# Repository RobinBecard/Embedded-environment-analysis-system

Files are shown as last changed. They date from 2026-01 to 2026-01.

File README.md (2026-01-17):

# Embedded Environment Analysis System




## Overview

This project is an **Autonomous Environmental Analysis Robot** designed to explore and monitor air quality in real-time. Built on an Arduino Mega platform, it integrates professional-grade sensors to measure atmospheric pressure, temperature, and multiple hazardous gases (CO, Smoke, CH4, Propane).

The system features a modular firmware architecture, separating motor control logic from sensor processing, making it highly maintainable and scalable.

---

## The System

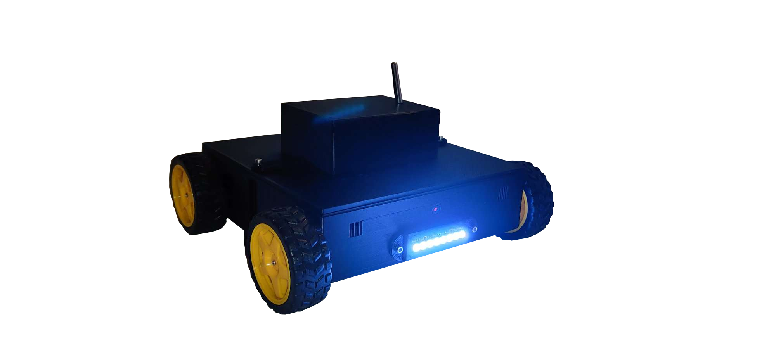
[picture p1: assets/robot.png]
System Photo

*Figure 1: Mobile analysis platform equipped with gas sensors and NeoPixel status indicators.*

---

## Key Features

* **Multi-Gas Detection:** Real-time PPM calculation for CO, Smoke, Methane, and Propane using calibrated MQ-series sensors.
* **Precision Telemetry:** Integration of the DFRobot ICP10111 for high-accuracy barometric pressure monitoring.
* **Modular Drive System:** 4-motor DC drive controlled via Adafruit Motor Shield, supporting full omnidirectional movement.
* **Visual Feedback:** 8-pixel NeoPixel LED strip for status signaling and alerts.
* **Remote Command Interface:** Serial-based control protocol for movement and data triggering.

---

## Hardware Components

| Component | Description |
| :--- | :--- |
| **Microcontroller** | Arduino Mega 2560 |
| **Motor Driver** | Adafruit Motor Shield (L293D based) |
| **Pressure Sensor** | DFRobot ICP10111 |
| **Temp Sensor** | DS18B20 (OneWire) |
| **Gas Sensors** | MQ-2 (Smoke/LPG), MQ-7 (CO) |
| **Illumination** | Adafruit NeoPixel Stick (8 RGB LEDs) |

---

## Project Structure

```text
Embedded-environment-analysis-system/
```text
Embedded-environment-analysis-system/
│   README.md
│   
├───app
├───assets
│   │   robot.png
│   │   
│   ├───arduino_mega/
│   │       
│   ├───battery
│   ├───bmp280_pressure_sensor/
│   │
│   ├───ds18b20_temp_sensor/
│   │
│   ├───esp32_cam/
│   │
│   ├───l293d/
│   │
│   └───motor/
├───docs/
│   │
│   └───datasheets/
│
├───EnvironmentalRobot_Firmware/
│   │
│   └───BTconfig/
│
└───mechanical
    ├───3d_printing/
    │
    └───components
        ├───arduino_mega/
        │
        ├───battery/
        │
        ├───bmp280_pressure_sensor/
        │
        ├───ds18b20_temp_sensor/
        │
        ├───l293d/
        │
        └───motor/
```

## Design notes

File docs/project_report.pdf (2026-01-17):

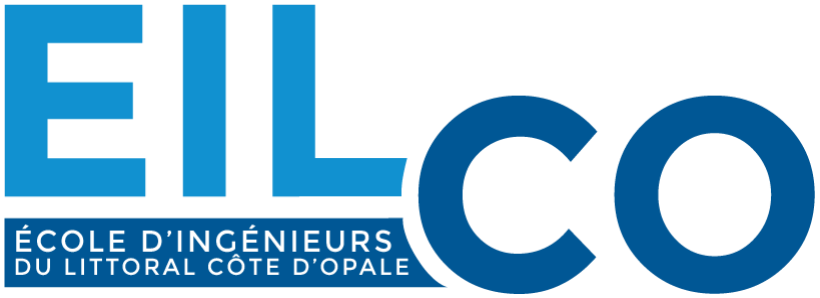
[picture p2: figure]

# Rapport de Projet “Système embarqué d’analyse d’environnement”

### Réalisé par:

### Robin BECARD Axel GROGNET Rémi DAMBRICOURT

### Professeur référent:

### André BIGAND

## Sommaire

## I/ Introduction

## II/ Organisation du projet

## - Dates limites

## III/ Cahier des charges

## - Objectifs - Contraintes, solutions et schémas fonctionnel - Comptes rendus de séances

## I/ Introduction

Dans un monde où l’insécurité ne cesse d’augmenter en partie à cause des catastrophes météorologiques, les services de secours sont en constante action. C’est ainsi que nous avons décidé d’intervenir pour assister ces services.

En effet, le but de ce projet est de réaliser un robot pouvant accéder à des zones restreintes et/ou dangereuses pour l’Homme. Il sera donc utile pour les secours en général lors d'événements catastrophiques (tremblement de terre, éboulement, etc) afin de détecter différentes fuites de gaz et de pouvoir observer ce qu’il s’y passe.

Notre objectif est de créer un prototype testable dans différents milieux afin de pouvoir l’améliorer pour une potentielle mise en vente. Les matériaux utilisés ne seront donc pas forcément les plus optimisés pour le projet vis-à-vis du temps et du budget que nous possédons pour le réaliser. De plus, le prototype ne sera pas étanche pour pouvoir réaliser une démonstration le jour de la soutenance.

## II/ Organisation du projet

### Dates Limites

Pour le bon avancement du projet, nous avons décidé de tout organiser en un planning pour le suivre le plus fidèlement possible.

Pour la commande des pièces, nous avons fixé la date du 15 octobre 2022 dans l’optique de pouvoir s’attaquer au montage du robot et aux différents tests avec le matériel. Nous avons envoyé la commande à Mr Ghislain le 14 octobre 2022.

Pour le montage du robot et des différents modules arduino, nous avions pour but de commencer vers le 30 octobre 2022, sauf que nous avons rencontré un problème. La commande est partie bien trop tard pour espérer commencer à cette date.
Pour pallier ce problème, nous avons décidé d’utiliser le matériel que nous avions déjà grâce à Robin BECARD pour commencer les différents tests du code Arduino que nous avons commencé à écrire entre la commande et la réception des composants.

Pour ce qui est du pré-rapport et du rapport final, nous sommes contraints de les rendre respectivement le 11 novembre 2022 et le jeudi 4 janvier 2023, dates que nous allons respecter.

La soutenance du projet se passera, sauf changement de date, le 11 janvier 2023.

## III/ Cahier des charges

### Objectifs

Ce projet doit répondre à 4 objectifs principaux :

- Se déplacer à distance sur plusieurs mètres
- Retourner un flux d’informations grâce aux capteurs via une “Interface Homme Machine” (IHM)
- Envoyer un flux vidéo en direct

### Contraintes et solutions

Pendant nos recherches, notre projet a été soumis à plusieurs contraintes auxquelles nous avons dû palier.

Premièrement, notre système embarqué est sensible aux intempéries, pour contrer cela nous avons décidé de réaliser un châssis et une protection pour contrer la pluie ou bien tout débris qui serait susceptible de tomber sur le robot. Pour que notre projet soit vraiment étanche, il faudrait venir colmater toutes ouvertures, mais nous ne le ferons pas pour agir facilement si nous avons un problème de pièces et pour pouvoir l’ouvrir le jour de la soutenance.

De plus, il doit également pouvoir se déplacer dans toutes les directions. Nous nous sommes donc penchés sur plusieurs solutions: le choix des chenilles fut énoncé en 1er mais fut vite écarté car trop complexe à mettre en œuvre. Le choix le plus évident était alors d’équiper notre système embarqué de 4 roues chacune équipé d’un moteur.

Il doit également être alimenté de façon continue et posséder une certaine autonomie. Nous sommes restés sur un choix assez simple, une batterie pour la carte arduino et les capteurs et une autre pour les moteurs, en effet ceux-ci consomment beaucoup et le robot doit garantir une autonomie suffisante pour ne pas tomber en panne. Mais suite à un problème avec la commande, nous n’avons qu’une seule batterie pour l’ensemble du système. Pour contrer cela, nous utiliserons une pile pour alimenter l'ESP 32-CAM.

La communication entre l’interface et le robot doit être rapide afin de garantir un bon contrôle du véhicule. L’utilisation d’une communication filaire était une des solutions prise en compte mais celles que l’on va privilégier sont la communication WIFI pour recevoir la vidéo et le Bluetooth afin de recevoir les informations des capteurs mais aussi d’envoyer les commandes de déplacement au robot. Cette technologie est contrainte à une certaine portée mais cela empêche le robot de se coincer avec un câble.

Afin de donner vie à notre système nous avons décidé de lui incorporer différents modules, tout d’abord le module ESP32-CAM, c’est ce qui va permettre d’envoyer en WIFI le flux vidéo de la caméra directement sur l’adresse http que générera l’ESP. Nous avons ensuite un module Bluetooth HC-05 qui permet de relier l’arduino, les moteurs et les capteurs directement à l’application sur téléphone. Notre robot étant tout d’abord un système d’analyse d’environnement, il lui fallait des capteurs afin de nous renvoyer des informations en direct sur son environnement. On l’a donc équipé d’un capteur de température, d’un capteur de pression et enfin 2 capteurs de gaz (un, spécifique au monoxyde de carbone, gaz plus compliqué à détecter par sa taille; et un autre plus général).

Pour mieux illustrer les solutions trouvés vous pouvez voir en annexe un schéma fonctionnel réalisé par nos soins (voir Figure 1).

### Compte rendu des séances

Afin de tenir compte de notre avancement, nous avons rédigé des rapports à la fin de chaque séance. Nous les avons condensés pour obtenir un texte plus lisible.

Lors de la première séance, le groupe a réfléchi sur les différents problèmes et solutions énoncés dans la partie “Contraintes et solutions” se situant plus haut dans le rapport. Pendant cette séance, on a sorti un premier schéma assez sommaire qui fut une base pour le schéma fonctionnel final. Cette première séance a grandement aidé pour la deuxième car nous avons directement commencé la recherche des différents composants nécessaires pour la bonne réalisation du projet.
A la séance d’après, nous avons eu une petite réunion avec notre référent pour lui tenir compte de notre avancement ainsi que de nos ambitions pour le projet, c’est notamment lui qui nous a décidé sur le choix de la communication bluetooth.
Après, nous avons pris le temps de créer une liste du matériel avec les intitulés exacts de chaque pièce et un lien pour trouver la dite pièce sur internet (voir Figure 2). C’est à ce moment-là qu'on a pris le temps de faire le schéma fonctionnel du robot.
La commande transmise à M. Ghislain, nous devions attendre l’arrivée des pièces. Pendant cette attente, on a commencé à coder différentes fonctions sur le fonctionnement des capteurs et des moteurs. Pour les tester, le site Tinkercad fut d’une grande aide. Grâce à ce dernier, on a pu simuler les différents composants que le robot possèdera à terme et vérifier leur bon fonctionnement. Le code pour demander au robot de se déplacer dans une direction ainsi que pour les capteurs est valide. (voir Figures 3, 4 et 5).
Lors des séances suivantes, on a commencé les tests avec le peu de matériel que nous avions à disposition et on a finalisé le pré-rapport. En annexes, on peut notamment voir différentes photos sur les capteurs, les moteurs et enfin une vision globale du montage avec les composants possédés avant le pré-rapport. (voir Figures 6, 7, 8, 9, 10 et 11)

Après cela, notre équipe s’est attaquée à la conception du châssis en impression 3D (voir Figures 12 et 13).
Suite à cela, nous avons récupéré les pièces manquantes dont l’ESP32-CAM, le module moteur arduino et les capteurs restants.
Entretemps, nous avons également trouvé comment résoudre notre plus gros problème, l’IHM. Nous avons trouvé un site nommé MIT App Inventor (https://appinventor.mit.edu) qui nous permet de créer notre propre application en codant par blocs et en connectant le lien http de l’ESP32-CAM par Bluetooth.
Après une autre séance et pas mal de travail pendant les vacances de Noël, nous avons finalement imprimé le châssis et continué l’IHM, cependant nous avons eu une contrainte technique sur le site qui nous empêche de recevoir à la fois la vidéo et les informations des capteurs. Pour pallier temporairement à ce problème nous avons décidé d’utiliser 2 appareils, l’un pour les commandes et les capteurs et l’autre pour la vidéo. (voir Figures 14, 15, 16)

Afin de retracer plus facilement l’avancement du projet, vous trouverez en annexe un diagramme de Gantt relatant nos recherches au cours du temps (voir Figure 17).

## Remerciements

Nous remercions notre référent Mr Bigand, pour son aide, son partage de connaissance en Arduino mais aussi pour nous avoir fourni du matériel que l’école n’a pas pu nous procurer. Nous remercions aussi Mr Poncin pour l’achat des pièces nécessaires à la fabrication du projet. Enfin nous remercions l’école de nous avoir permis de réaliser ce projet et pour nous avoir financé.

## Annexes

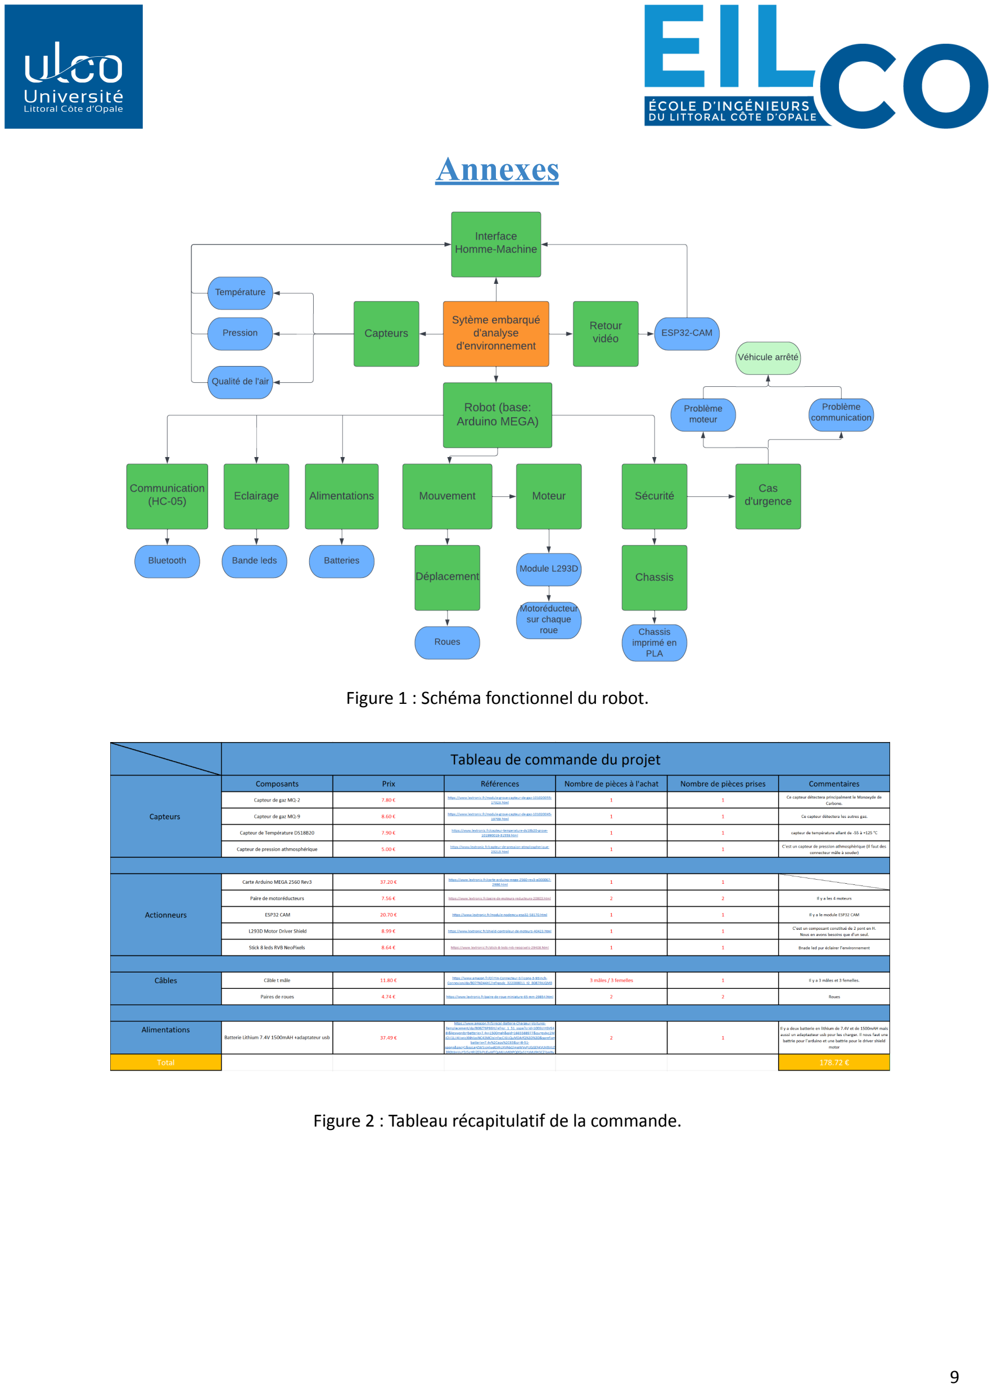
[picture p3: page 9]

Figure 1 : Schéma fonctionnel du robot.

Figure 2 : Tableau récapitulatif de la commande.

## Annexes

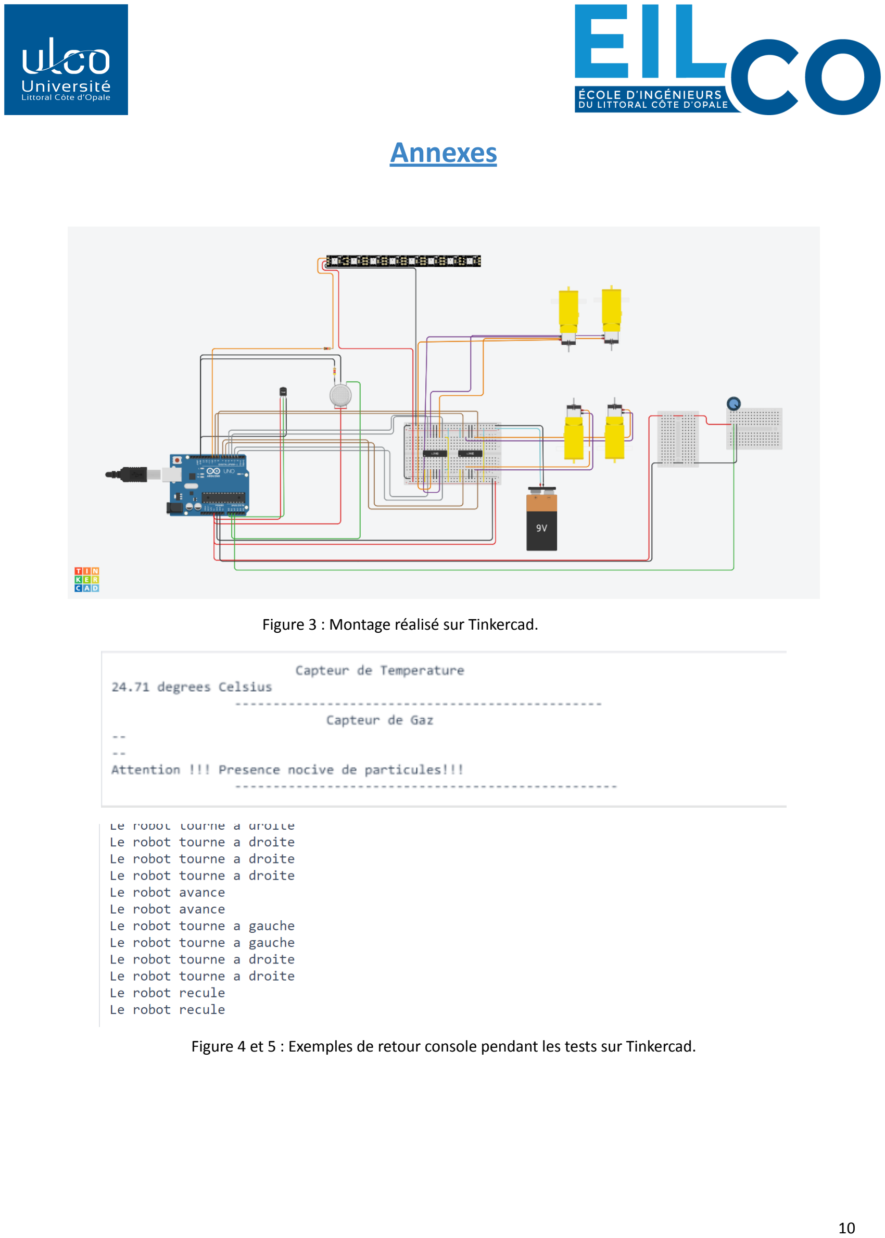
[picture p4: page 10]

Figure 3 : Montage réalisé sur Tinkercad.

Figure 4 et 5 : Exemples de retour console pendant les tests sur Tinkercad.

## Annexes

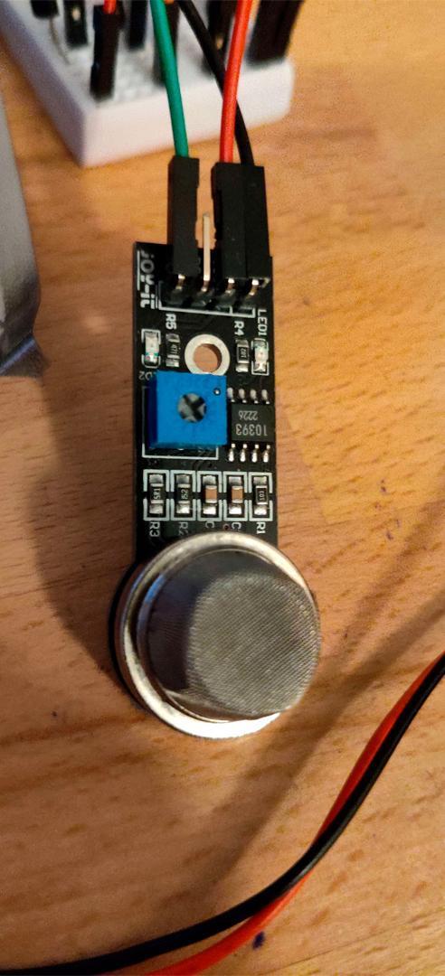
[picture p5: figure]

Figure 6 : Capteur de gaz.

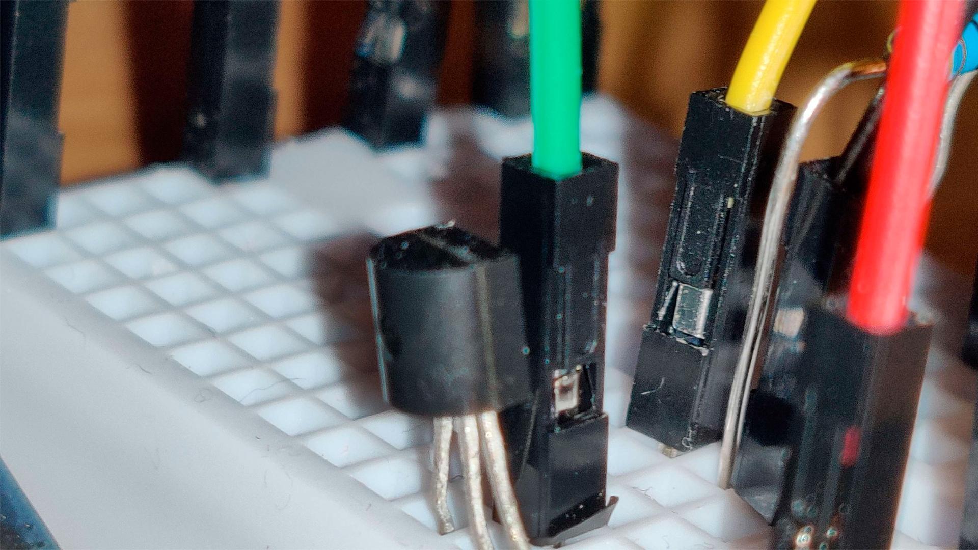
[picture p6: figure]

Figure 7 : Capteur de température.

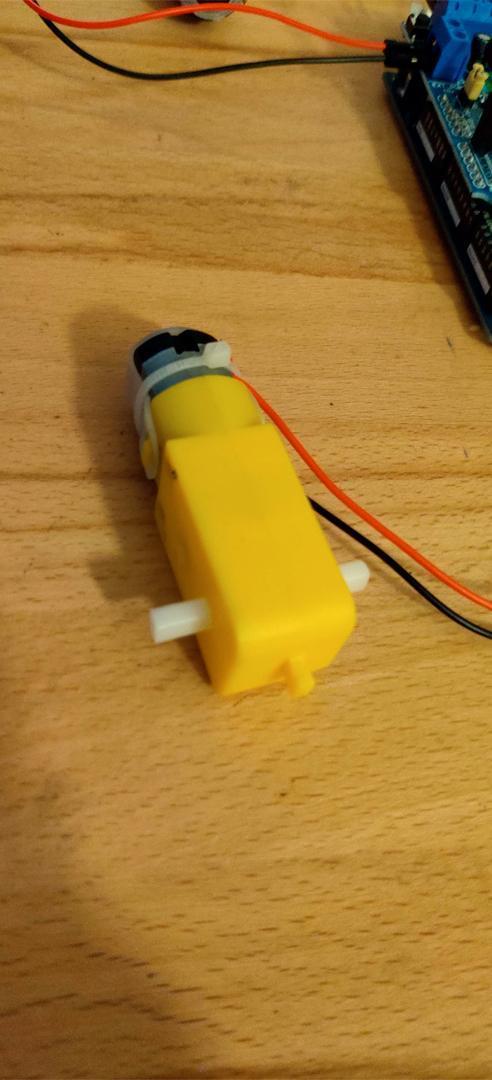
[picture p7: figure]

Figure 8 : Un des motoréducteurs qui contrôlera les roues.

## Annexes

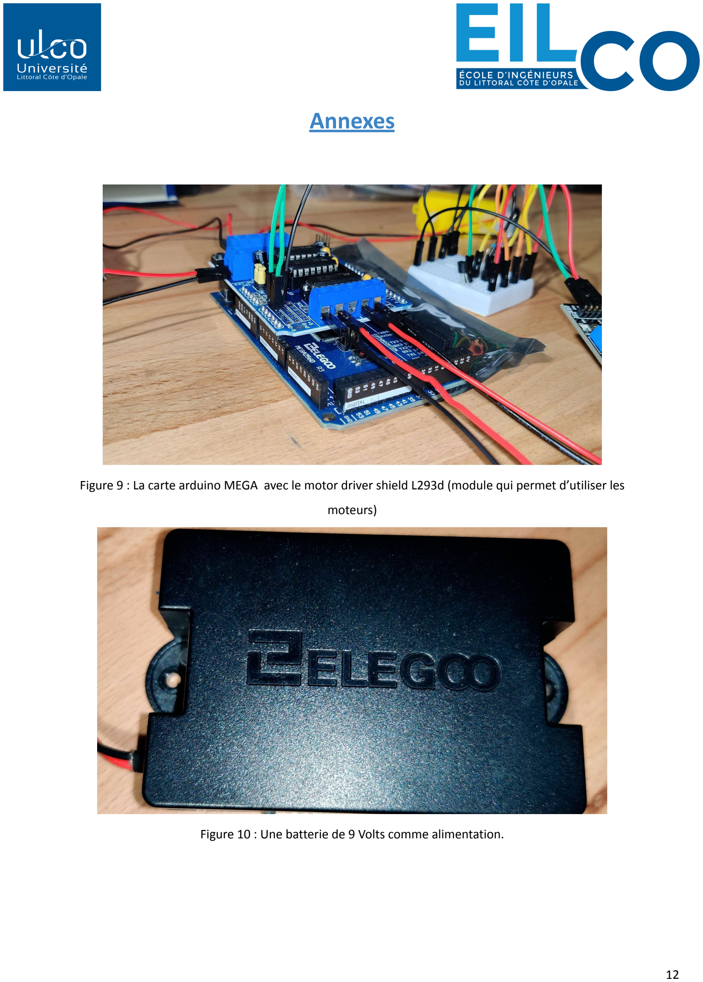
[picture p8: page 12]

Figure 9 : La carte arduino MEGA avec le motor driver shield L293d (module qui permet d’utiliser les

moteurs)

Figure 10 : Une batterie de 9 Volts comme alimentation.

## Annexes

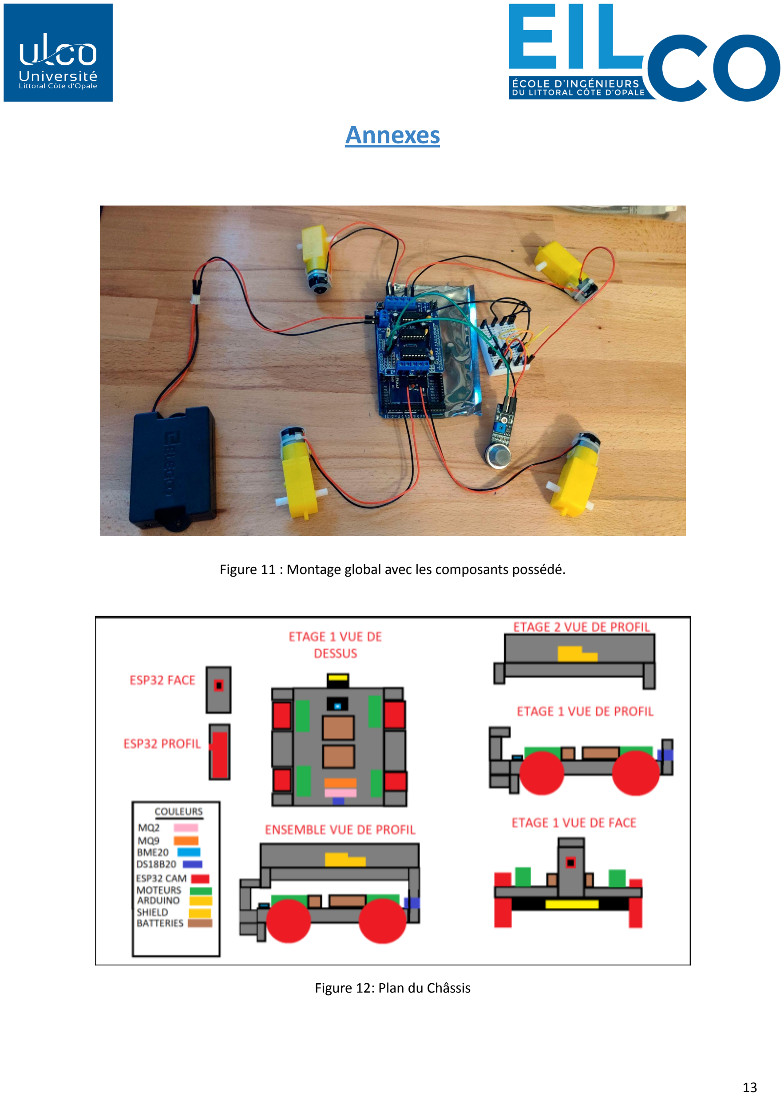
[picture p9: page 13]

Figure 11 : Montage global avec les composants possédé.

Figure 12: Plan du Châssis

## Annexes

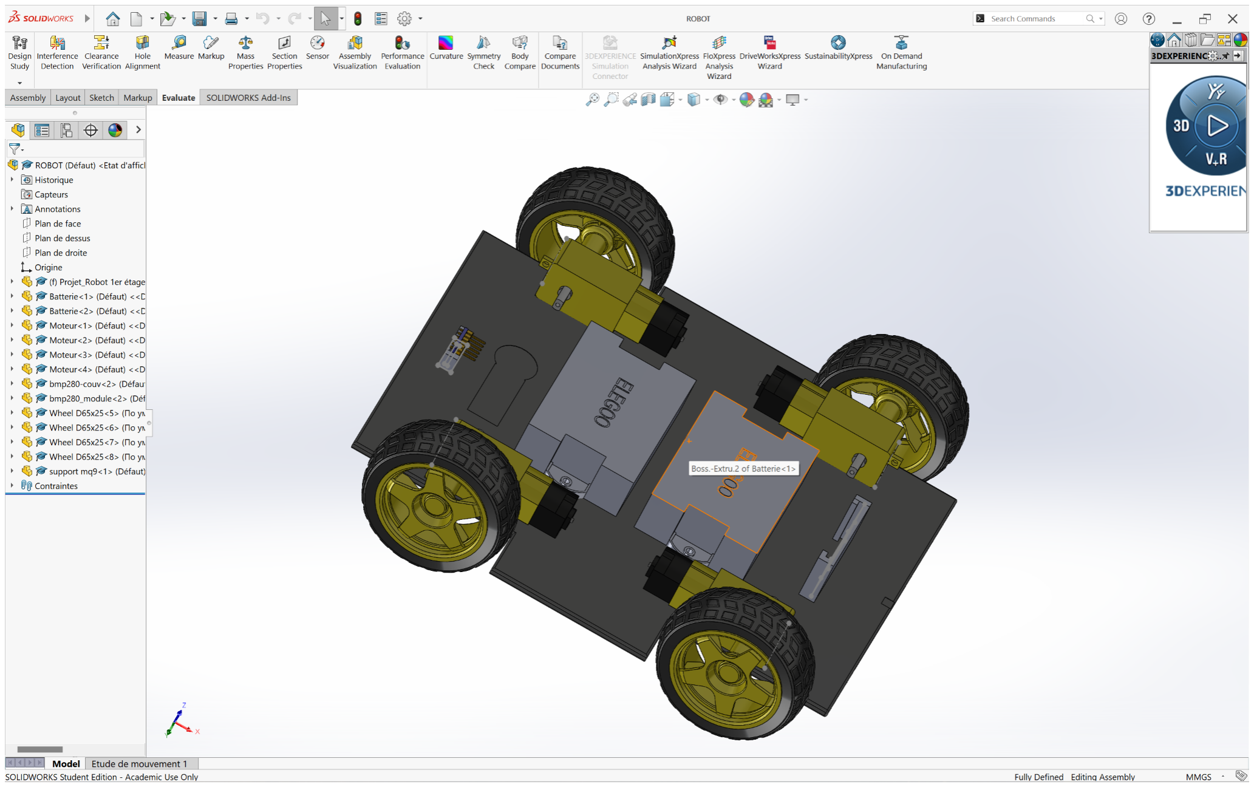
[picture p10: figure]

Figure 13: Châssis en 3d sur SolidWorks

## Annexes

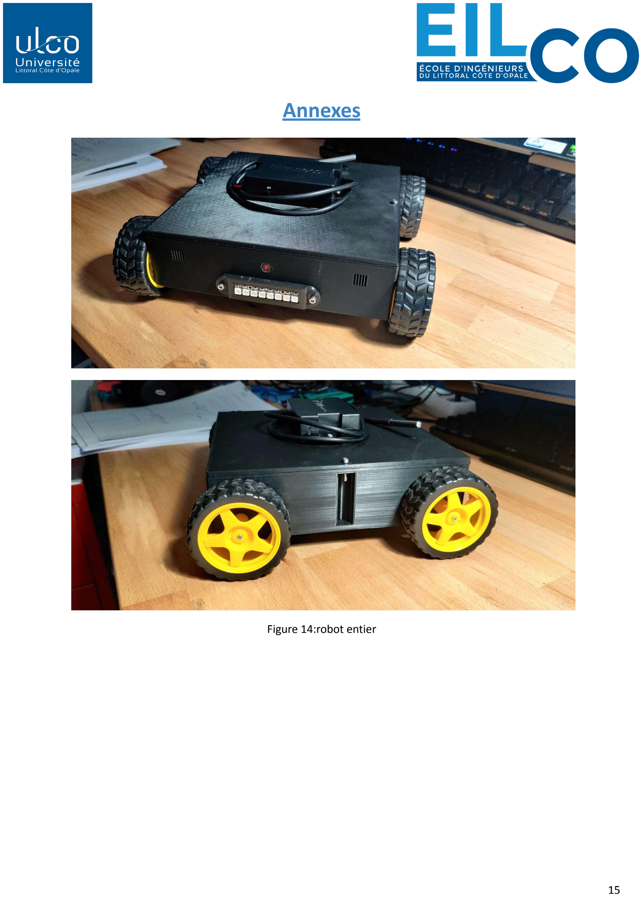
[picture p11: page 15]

Figure 14:robot entier

## Annexes

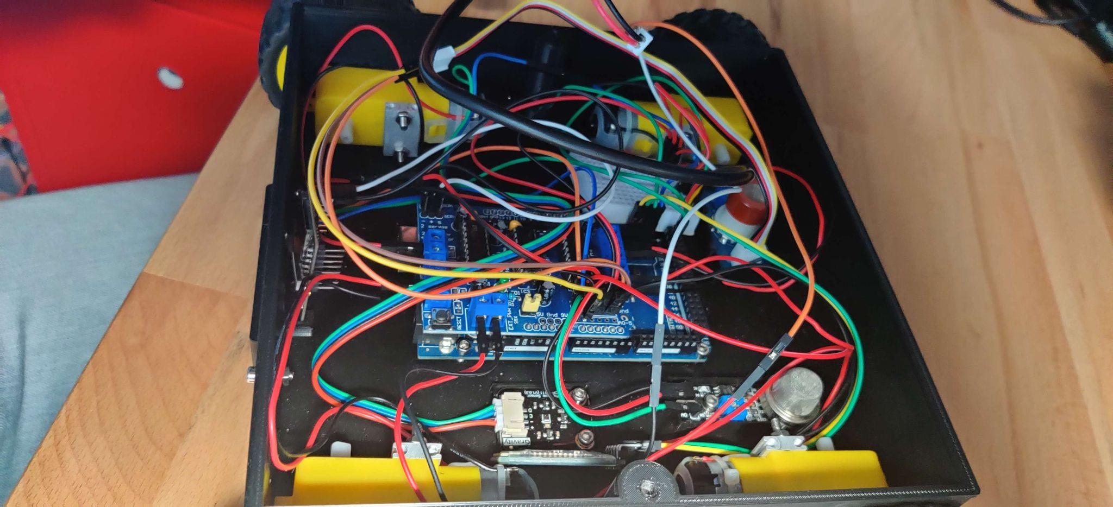
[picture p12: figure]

Figure 15: intérieur étage 1

## Annexes

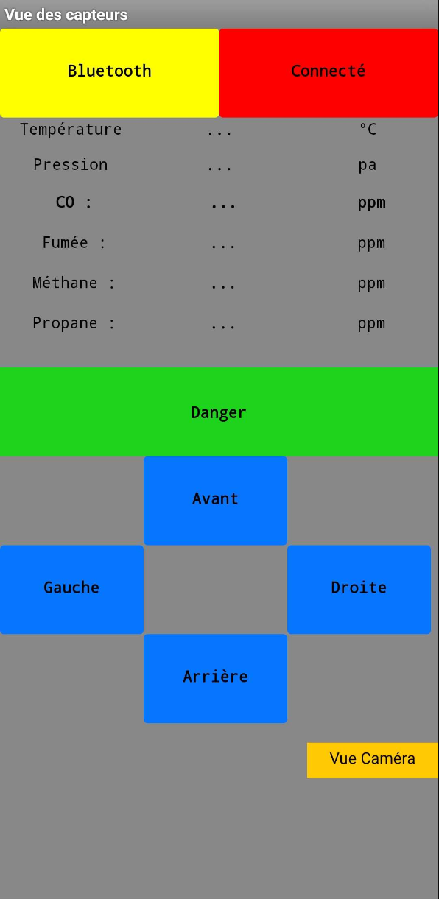
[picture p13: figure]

Figure 16: application vue capteurs

## Annexes

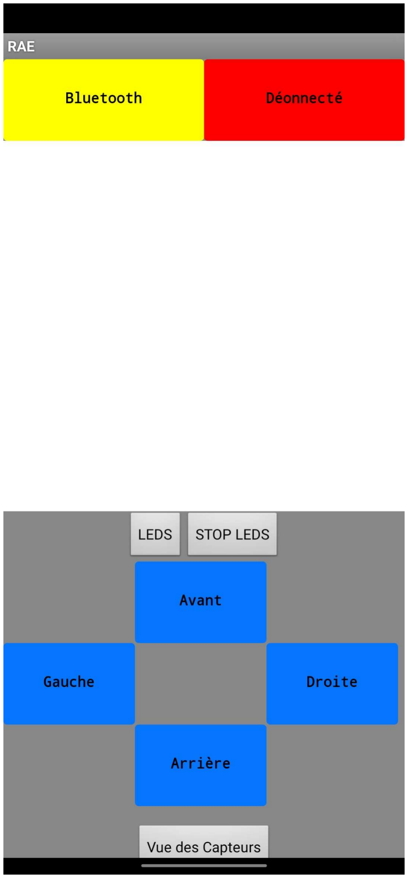
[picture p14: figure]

Figure 17: application vue caméra

## Annexes

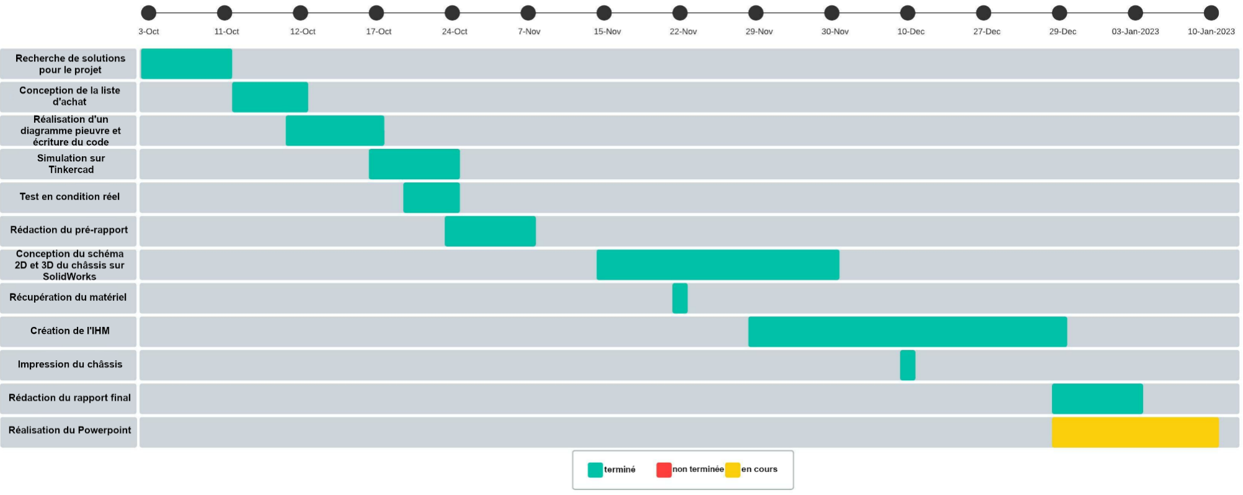
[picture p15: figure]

Figure 18: Diagramme de Gantt

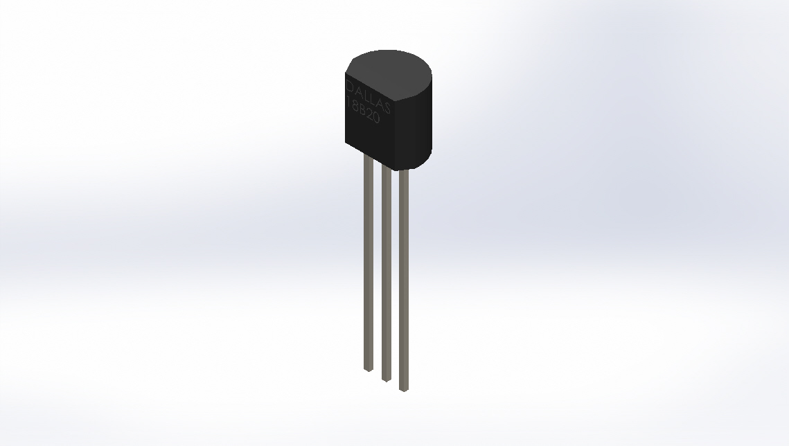
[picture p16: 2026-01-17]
assets/ds18b20_temp_sensor/ds18b20_01.JPG

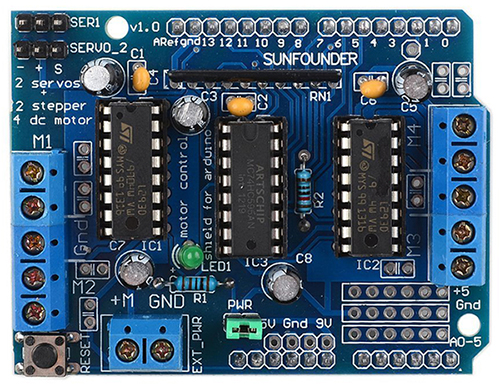
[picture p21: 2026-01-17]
assets/l293d/l293d_01.jpg

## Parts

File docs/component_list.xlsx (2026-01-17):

 | Tableau de commande du projet
Capteurs | Composants | Prix | Références | Nombre de pièces à l'achat | Nombre de pièces prises | Commentaires | Dimenstion (mm)
 | Capteur de gaz MQ-2 | 7.80 € | https://www.lextronic.fr/module-grove-capteur-de-gaz-101020055-17323.html | 1 | 1 | Ce capteur détectera principalment le Monoxyde de Carbone. | 52 x 20 x 13
 | Capteur de gaz MQ-9 | 8.60 € | https://www.lextronic.fr/module-grove-capteur-de-gaz-101020045-19709.html | 1 | 1 | Ce capteur détectera les autres gaz. | 42 x 24 x 27
 | Capteur de Température DS18B20 | 7.90 € | https://www.lextronic.fr/capteur-temperature-ds18b20-grove-101990019-31559.html | 1 | 1 | capteur de température allant de -55 à +125 °C | 5x5x3
 | Capteur de pression athmosphérique | 5.00 € | https://www.lextronic.fr/capteur-de-pression-atmplospherique-23213.html | 1 | 1 | C'est un capteur de pression athmosphèrique (il faut des connecteur mâle à souder) | 20x10x1.5
Actionneurs | Carte Arduino MEGA 2560 Rev3 | 37.20 € | https://www.lextronic.fr/carte-arduino-mega-2560-rev3-a000067-2986.html | 1 | 1 |  | 430x102x15
 | Paire de motoréducteurs | 7.56 € | https://www.lextronic.fr/paire-de-moteurs-reducteurs-20803.html | 2 | 2 | Il y a les 4 moteurs | 70x20x2.5
 | ESP32 CAM | 13.00 € | https://www.lextronic.fr/module-nodemcu-esp32-58170.html | 1 | 1 | Il y a le module ESP32 CAM | 40.5x27.0x5
 | L293D Motor Driver Shield | 8.99 € | https://www.lextronic.fr/shield-controleur-de-moteurs-40423.html | 1 | 1 | C'est un composant constitué de 2 pont en H. Nous en avons besoins que d'un seul. | 70x53x20
 | Stick 8 leds RVB NeoPixels | 8.64 € | https://www.lextronic.fr/stick-8-leds-rvb-neopixels-29408.html | 1 | 1 | Bnade led pur éclairer l'environnement | 51,1 x 10,22
Câbles | Paires de roues | 4.74 € | https://www.lextronic.fr/paire-de-roue-miniature-65-mm-29854.html | 2 | 2 | Roues
Alimentations | Batterie Lithium 3.7V 2000mAh | 37.49 € | https://www.amazon.fr/Sirecal-Batterie-Chargeur-Voitures-Remplacement/dp/B08Z76P86H | 1 | 1
 | MT3608 | 12.48 € | https://www.amazon.fr/TECNOIOT-MT3608-Module-Booster-Arduino/dp/B07G4KWV6S | 5 | 1
Total |  |  |  |  |  | 171.70 €

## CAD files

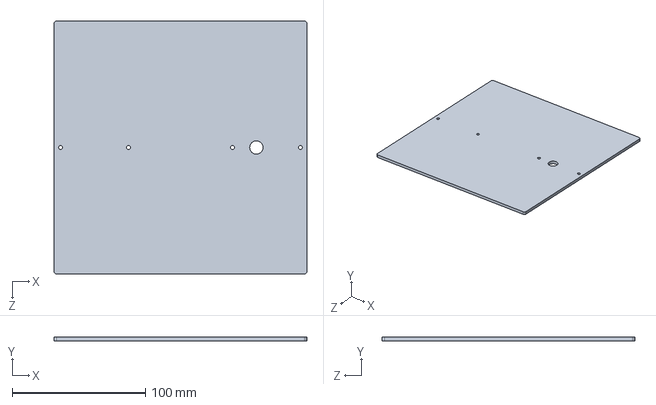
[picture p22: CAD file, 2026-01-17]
mechanical/3d_printing/body_cover.SLDPRT
190.0 x 3.00 x 190.0 mm

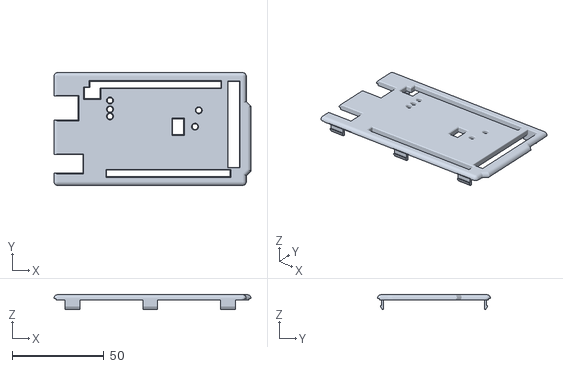
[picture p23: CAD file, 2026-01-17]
mechanical/components/arduino_mega/arduino_mega_top.stl
107.1 x 61.3 x 8.00

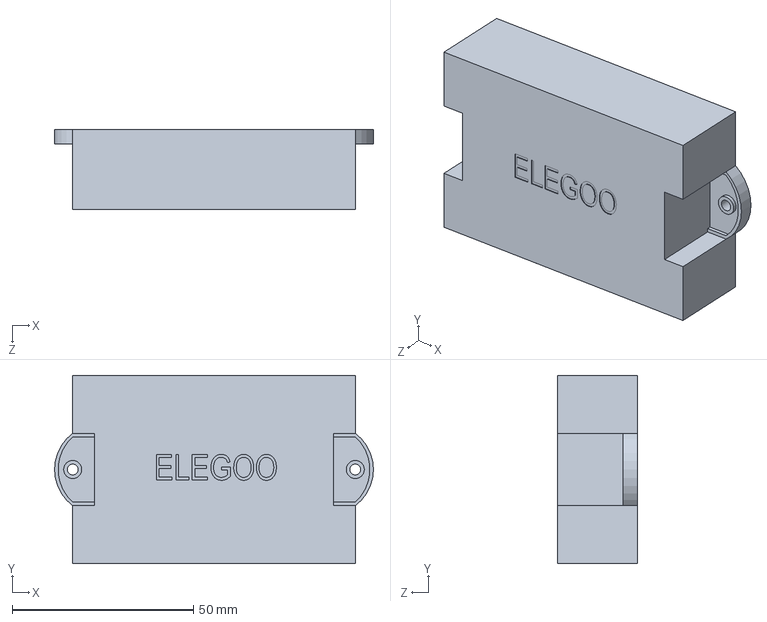
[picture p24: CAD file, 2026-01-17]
mechanical/components/battery/battery.SLDPRT
88.0 x 52.0 x 22.0 mm

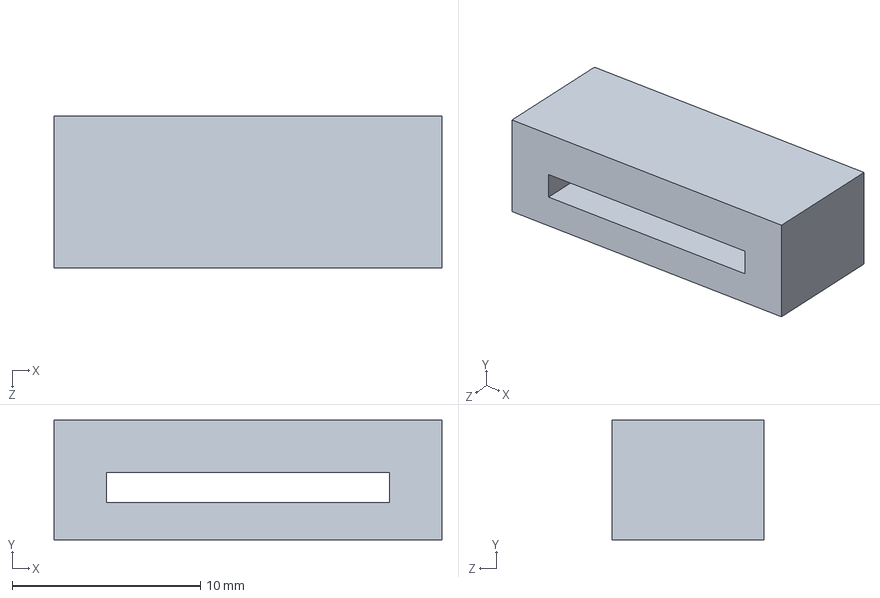
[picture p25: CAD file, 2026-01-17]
mechanical/components/bmp280_pressure_sensor/bmp280-couv.SLDPRT
20.6 x 6.37 x 8.07 mm

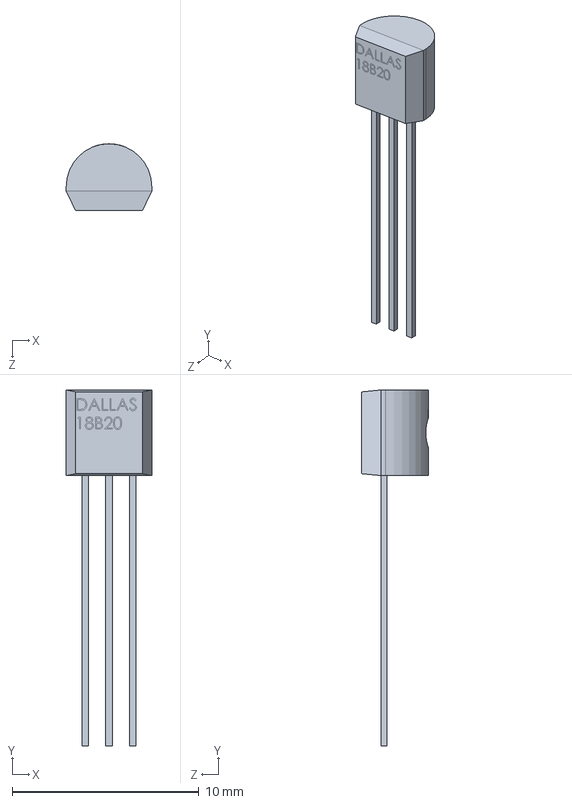
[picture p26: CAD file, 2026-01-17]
mechanical/components/ds18b20_temp_sensor/ds18b20.SLDPRT
4.58 x 19.0 x 3.56 mm

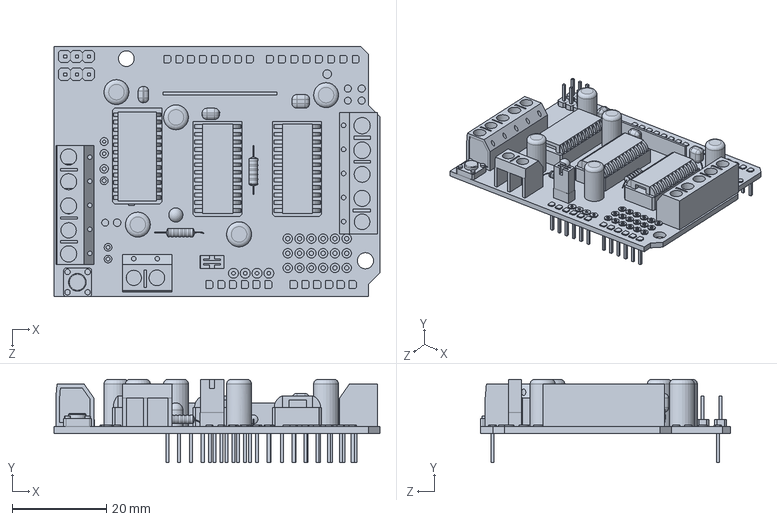
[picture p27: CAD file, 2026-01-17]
mechanical/components/l293d/l293d.SLDPRT
69.1 x 17.7 x 53.1 mm

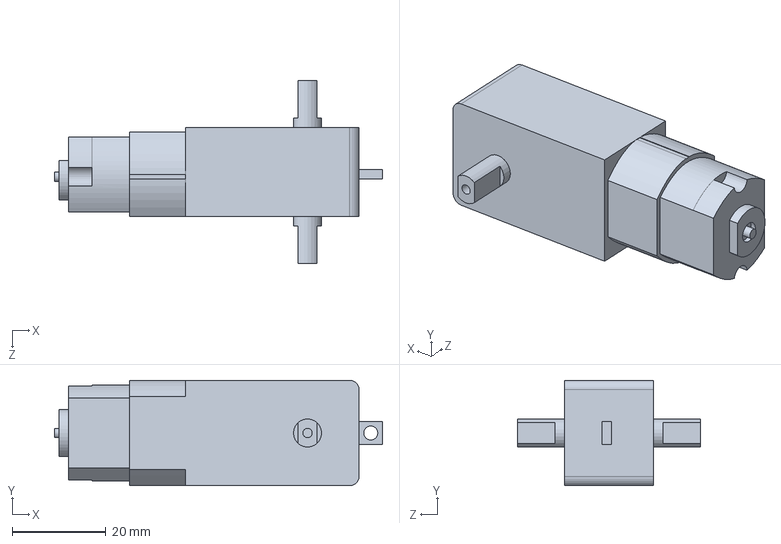
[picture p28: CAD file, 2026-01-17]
mechanical/components/motor/motor.SLDPRT
70.0 x 22.5 x 39.0 mm

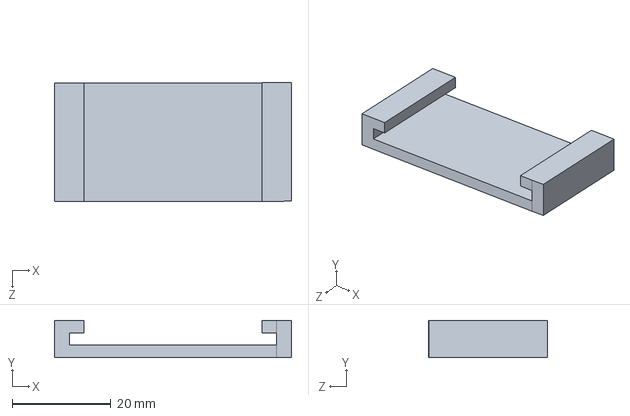
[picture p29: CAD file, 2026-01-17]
mechanical/3d_printing/mq9_support.SLDPRT
48.0 x 7.50 x 24.1 mm

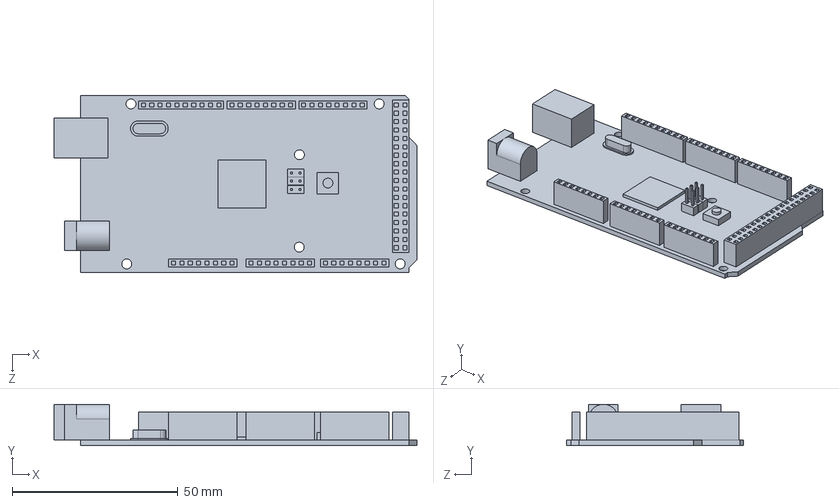
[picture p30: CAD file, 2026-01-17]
mechanical/components/arduino_mega/arduino_mega.SLDPRT
109.6 x 12.5 x 53.3 mm

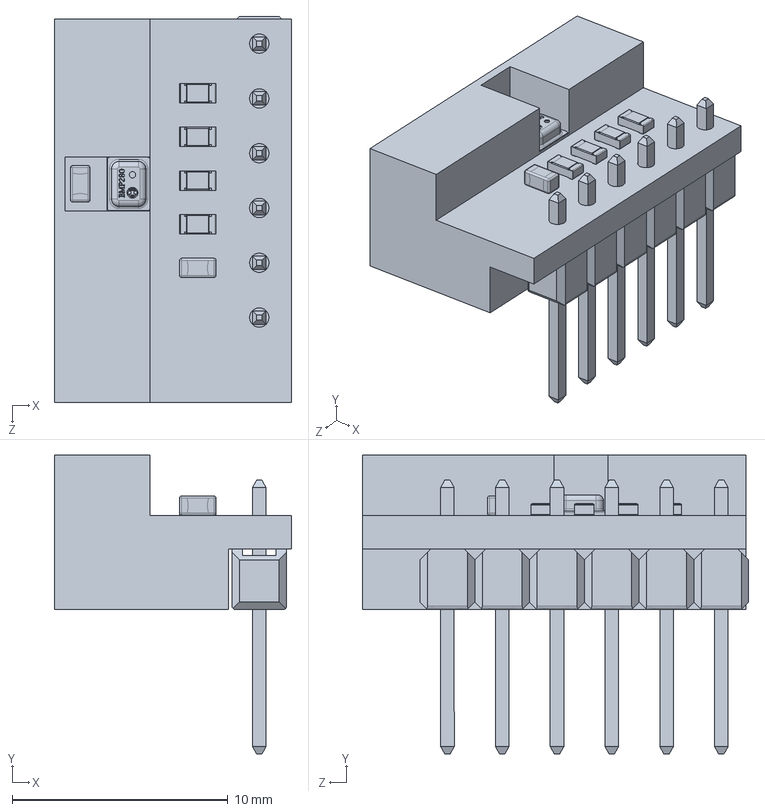
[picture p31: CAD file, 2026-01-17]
mechanical/components/bmp280_pressure_sensor/bmp280_module.SLDPRT
11.0 x 13.9 x 17.9 mm

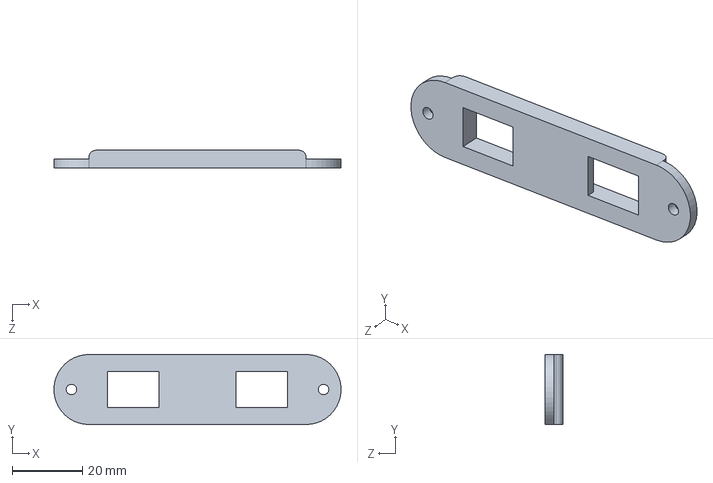
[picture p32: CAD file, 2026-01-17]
mechanical/3d_printing/led_suport.SLDPRT
81.9 x 20.0 x 5.02 mm

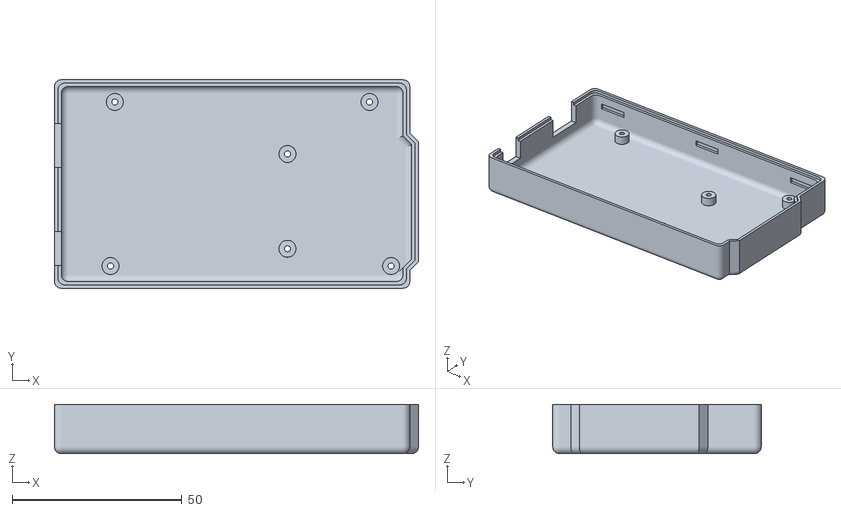
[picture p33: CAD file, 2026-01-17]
mechanical/components/arduino_mega/arduino_mega_bottom.stl
107.1 x 61.3 x 14.5

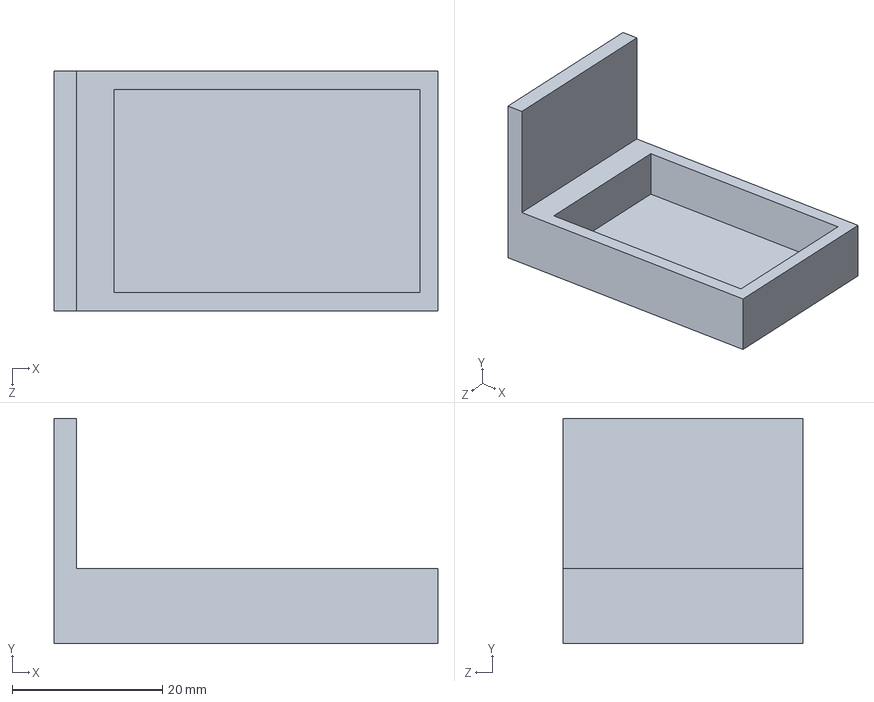
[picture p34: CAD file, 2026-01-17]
mechanical/3d_printing/esp32_support.SLDPRT
51.1 x 30.0 x 32.0 mm

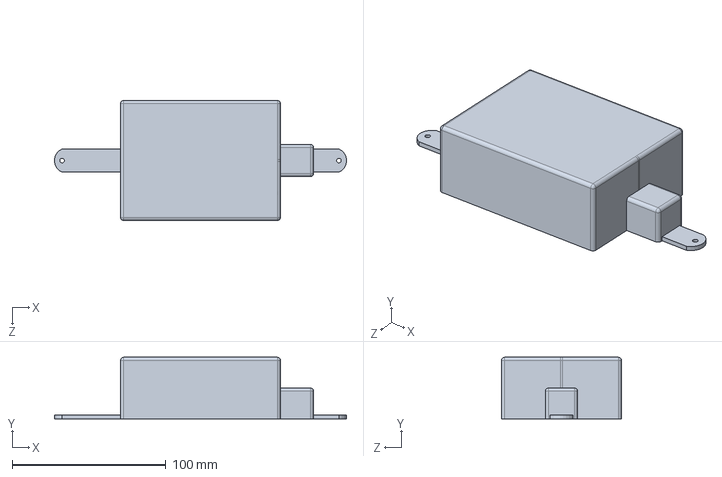
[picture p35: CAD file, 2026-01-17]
mechanical/3d_printing/battery_cover.SLDPRT
189.9 x 40.0 x 78.0 mm

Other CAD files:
mechanical/3d_printing/body.SLDPRT

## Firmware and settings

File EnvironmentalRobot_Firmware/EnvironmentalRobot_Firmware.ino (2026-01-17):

#include "config.h"
#include "motors.h"
#include "sensors.h"

int current_speed = 230;

void setup() {
    Serial.begin(9600);
    Serial1.begin(9600);
    
    initMotors(current_speed);
    initSensors();
    
    Serial.println("System Ready!");
}

void loop() {
    if (Serial1.available() > 0) {
        int state = Serial1.read();
        executeCommand(state);
    }
}

void executeCommand(int state) {
    switch(state) {
        case 1: avancer(); break;
        case 2: reculer(); break;
        case 3: gauche();  break;
        case 4: droite();  break;
        case 5: stopMotors(); break;
        case 6: stopMotors(); updateAndSendData(); break;
        case 7: setLeds(true);  break;
        case 8: setLeds(false); break;
    }
}

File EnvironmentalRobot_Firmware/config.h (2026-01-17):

#ifndef CONFIG_H
#define CONFIG_H

#include <Arduino.h>

// --- PINS ---
#define PIN_NEOPIXEL 24
#define PIN_ONE_WIRE 22
#define PIN_GAZ_MQ   0
#define PIN_GAZ_CO   1

// --- SENSORS CONFIG ---
const int NUM_PIXELS = 8;
const int RL_VALUE = 1;
const float FACTEUR_R0 = 9.8;

const int CALIB_SAMPLES = 50;
const int CALIB_INTERVAL = 500;
const int READ_SAMPLES = 5;
const int READ_INTERVAL = 50;

// --- GAS IDENTIFIERS ---
enum GasType { GPL, CO, FUMEE, CH4, PROPANE, ALCOOL };

// --- CALIBRATION CURVES ---
const float CourbeCO[3]    = {3.91, -2.4, -0.667};
const float CourbeFUMEE[3] = {2.3, 0.5, -0.45};
const float CourbeCH4[3]   = {2.3, 0.47, -0.37};
const float CourbePROP[3]  = {2.3, 0.23, -0.46};

#endif

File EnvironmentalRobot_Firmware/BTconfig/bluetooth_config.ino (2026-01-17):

#include <SoftwareSerial.h>

SoftwareSerial mySerial(10, 11); // RX, TX

void setup() {
  Serial.begin(9600);
  pinMode(9,OUTPUT); digitalWrite(9,HIGH);
  Serial.println("Enter AT commands:");
  mySerial.begin(38400);
}

void loop()
{
  if (mySerial.available())  
  Serial.write(mySerial.read());
  
  if (Serial.available())  
  mySerial.write(Serial.read());
}

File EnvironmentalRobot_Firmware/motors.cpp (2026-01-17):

#include <AFMotor.h>
#include "motors.h"

AF_DCMotor m1(1), m2(2), m3(3), m4(4);

void initMotors(int speed) {
    m1.setSpeed(speed); m2.setSpeed(speed);
    m3.setSpeed(speed); m4.setSpeed(speed);
}

void avancer() {
    m1.run(BACKWARD); m2.run(FORWARD);
    m3.run(FORWARD);  m4.run(BACKWARD);
}

void reculer() {
    m1.run(FORWARD);  m2.run(BACKWARD);
    m3.run(BACKWARD); m4.run(FORWARD);
}

void droite() {
    m1.run(FORWARD); m2.run(FORWARD);
    m3.run(FORWARD); m4.run(FORWARD);
}

void gauche() {
    m1.run(BACKWARD); m2.run(BACKWARD);
    m3.run(BACKWARD); m4.run(BACKWARD);
}

void stopMotors() {
    m1.run(RELEASE); m2.run(RELEASE);
    m3.run(RELEASE); m4.run(RELEASE);
}

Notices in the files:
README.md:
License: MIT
